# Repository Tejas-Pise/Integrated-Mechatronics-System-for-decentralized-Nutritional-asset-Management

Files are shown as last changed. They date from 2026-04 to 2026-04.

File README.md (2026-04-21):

# Integrated Mechatronics System for Decentralized Nutritional Asset Management

A cyber-physical public distribution platform for controlled, auditable, and low-friction ration dispensing. The system integrates embedded sensing and actuation (ESP32), edge orchestration (Raspberry Pi), and cloud-backed entitlement records (Firebase) to support accountable nutritional asset delivery at decentralized kiosks.

## Abstract

Conventional ration distribution pipelines in decentralized settings are vulnerable to leakage, weak traceability, and inconsistent beneficiary verification. This project proposes and implements a mechatronic kiosk architecture that combines multimodal identity checks, quota-aware dispensing logic, closed-loop gravimetric control, and transaction logging. The design objective is to reduce fraud opportunity, improve service throughput, and maintain verifiable audit trails while preserving practical deployability under constrained infrastructure.

## Research Motivation and Problem Statement

Public food distribution systems must satisfy three constraints simultaneously:

1. Identity assurance: only eligible beneficiaries should receive allocations.
2. Quantity fidelity: physical dispensed mass should match entitlement and payment policy.
3. Traceable accountability: each transaction should be reconstructable for post-hoc audit.

This repository operationalizes those constraints as a working prototype with a dual-node hardware-software stack and explicit machine-level protocol between nodes.

## Contributions

1. A modular edge architecture separating hard real-time control (ESP32) from business workflow orchestration (Raspberry Pi).
2. A serial command/event protocol for deterministic coordination of scan, verification, and dispense phases.
3. A closed-loop dispensing routine based on load-cell feedback and target-mass termination.
4. A cloud integration layer for entitlement lookup, monthly quota accounting, and transaction persistence.
5. An operator-facing kiosk interface with voice prompts, stock alerts, and payment flow scaffolding.

## High-Level System Architecture

The platform is organized into three cooperating layers:

1. Embedded control plane (ESP32): sensor IO, actuator control, weight feedback, and stock telemetry.
2. Edge orchestration plane (Raspberry Pi): user journey, identity flow, payment logic, UI/voice interaction, and cloud sync.
3. Cloud data plane (Firebase): user records, dispensed quota totals, and transaction logs.

### End-to-End Workflow

1. User initiates session at kiosk.
2. RFID scan and optional manual card entry identify candidate beneficiary.
3. Fingerprint match confirms identity linkage.
4. Cloud quota lookup determines remaining monthly entitlement and scheme type.
5. If paid scheme, UPI QR is generated and payment confirmation is awaited.
6. Raspberry Pi requests ESP32 dispensing to target mass.
7. ESP32 streams real-time weight and sends completion event.
8. Transaction is recorded and monthly dispensed counter is updated.
9. Hopper stock telemetry is periodically published and low-stock alerts are raised.

## Repository Layout

```text
.
|-- ESP32/
|   `-- ration_kiosk_esp32/
|       `-- ration_kiosk_esp32.ino
|-- Firebase/
|   `-- database_rules.json
|-- raspberry_pi/
|   |-- cloud.py
|   |-- config.py
|   |-- main.py
|   |-- payment.py
|   |-- requirements.txt
|   |-- stock.py
|   |-- uart_comm.py
|   |-- ui.py
|   `-- voice.py
`-- README.md
```

## Implementation Status (As of 2026-04-21)

Implemented:

1. ESP32 firmware with RFID, fingerprint scan routine, load-cell integration, dispensing control, and ultrasonic stock reporting.
2. Raspberry Pi orchestration flow in main controller with authentication, quota check, payment branch, dispensing callbacks, and transaction write.
3. Firebase access module for user lookup, quota calculation, transaction append, and stock updates.
4. Pygame-based kiosk UI screens and voice prompt layer.

Partially implemented or placeholder behavior:

1. Payment verification currently returns success via placeholder logic and must be replaced by gateway callback/webhook integration.
2. Manual ration-card entry UI is stubbed in controller.
3. Firebase security rules file exists but is currently empty and requires deployment-grade hardening.
4. Python dependency list is currently empty and should be pinned before production deployment.

## ESP32 Firmware Specification

Firmware file: ESP32/ration_kiosk_esp32/ration_kiosk_esp32.ino

### Sensors and Actuators

1. RFID: MFRC522 (SPI).
2. Fingerprint sensor: UART-based Adafruit-compatible module.
3. Mass measurement: HX711 + load cell.
4. Hopper level: ultrasonic distance sensor.
5. Dispense actuation: stepper motor + driver and solenoid gate.

### Control Semantics

1. Dispenser starts with tare reset, solenoid open, and stepper enable.
2. Weight samples are emitted during dispensing.
3. Dispensing halts when current weight exceeds or equals target mass.
4. Stock distance is reported periodically; threshold breach emits low-stock event.

## UART Protocol Contract

### Commands (Raspberry Pi -> ESP32)

1. SCAN_RFID
2. SCAN_FINGER
3. DISPENSE:<target_weight_kg>
4. STOP
5. TARE
6. WEIGHT?

### Events/Responses (ESP32 -> Raspberry Pi)

1. ESP32_READY
2. RFID_SCANNING
3. RFID:<UID_HEX>
4. RFID_TIMEOUT
5. FP_SCANNING
6. FP_MATCH:<finger_id>
7. FP_NO_MATCH
8. FP_TIMEOUT
9. DISPENSE_START
10. WEIGHT:<kg>
11. DISPENSE_DONE:<kg>
12. DISPENSE_STOP
13. STOCK:<distance_cm>
14. STOCK_LOW:<distance_cm>

## Raspberry Pi Software Architecture

### Module Responsibilities

1. raspberry_pi/main.py: session state flow, authentication pipeline, scheme-specific branching, and transaction finalization.
2. raspberry_pi/uart_comm.py: serial transport abstraction, callback dispatch, blocking scan primitives, and dispense streaming callbacks.
3. raspberry_pi/cloud.py: Firebase initialization and CRUD-style service methods.
4. raspberry_pi/payment.py: UPI QR generation, payment polling scaffold, and pricing computation.
5. raspberry_pi/stock.py: stock event handling, cloud stock update, and external alert trigger.
6. raspberry_pi/ui.py: touchscreen workflows implemented in pygame.
7. raspberry_pi/voice.py: non-blocking spoken prompts via gTTS with system fallback.
8. raspberry_pi/config.py: deployment constants for serial, pricing, UI dimensions, and policy thresholds.

### Logical State Machine

At a conceptual level, the controller behaves as a finite-state process:

1. S0 Idle/Welcome
2. S1 Identity Capture (RFID/manual card)
3. S2 Biometric Verification
4. S3 Cloud Quota Evaluation
5. S4 Scheme Branch (FREE or PAID)
6. S5 Payment (PAID branch only)
7. S6 Dispensing
8. S7 Transaction Commit
9. S8 Session Completion -> S0

Any validation failure routes to error display and restart from S0.

## Data Model (Firebase, Current Usage)

Observed key paths in current code:

1. users/<ration_card_no>
2. users/<ration_card_no>/dispensed/<YYYY-MM>
3. transactions/<ration_card_no>/<auto_key>
4. stock/hopper_distance_cm
5. stock/last_updated

Representative user fields:

1. name
2. ration_card
3. rfid_uid
4. fingerprint_id
5. monthly_quota_kg
6. scheme_type
7. family_size

## Experimental and Deployment Prerequisites

### Hardware

1. ESP32 dev board
2. Raspberry Pi 3/4/5
3. MFRC522 RFID module
4. UART fingerprint sensor
5. HX711 + calibrated load cell
6. Ultrasonic sensor
7. Stepper motor and driver
8. Solenoid actuator
9. Protected power stage, fusing, and relay/driver isolation where required

### Software

1. Arduino IDE 2.x (ESP32 toolchain)
2. Python 3.10+ on Raspberry Pi
3. Firebase project with Realtime Database
4. Linux utilities for audio playback (for example mpg123 or espeak fallback)

## Reproducible Setup Procedure

### A. Flash and Validate ESP32

1. Open ESP32/ration_kiosk_esp32/ration_kiosk_esp32.ino in Arduino IDE.
2. Install required libraries: MFRC522, Adafruit Fingerprint Sensor Library, HX711.
3. Select ESP32 Dev Module and set baud to 115200.
4. Confirm pin mapping against physical wiring.
5. Upload and verify serial startup event ESP32_READY.

### B. Configure Raspberry Pi Runtime

1. Create Python virtual environment.
2. Install dependencies required by current modules (serial, pygame, firebase-admin, qrcode, pillow, gTTS, requests).
3. Place Firebase service account JSON at raspberry_pi/firebase_service_key.json or update path in cloud module.
4. Update raspberry_pi/config.py with project-specific database URL, pricing, UART port, and payment identity.
5. Launch controller from raspberry_pi/main.py.

### C. Configure Firebase

1. Populate beneficiary records with ration card, RFID UID, fingerprint ID, quota, and scheme type.
2. Add database security rules before field testing.
3. Validate read/write privileges using least-privilege principle.

## Calibration and Validation Protocol

For defensible performance reporting, calibrate and evaluate under controlled conditions.

1. Load-cell calibration:
   Use at least three known masses spanning expected dispense range and fit scale factor.
2. Dispense accuracy test:
   For each target mass, run repeated trials and report mean absolute error and standard deviation.
3. Biometric flow reliability:
   Measure false rejection events and timeout rate across user cohorts.
4. End-to-end latency:
   Report timing from session start to dispense completion under free and paid branches.
5. Stock alert validity:
   Confirm threshold crossing behavior against measured hopper levels.

Useful metrics include:

1. Mean dispense error (kg)
2. 95th percentile session duration (s)
3. Successful first-attempt biometric rate (%)
4. Cloud commit success rate (%)
5. Stock alert precision/recall against manual ground truth

## Security, Safety, and Ethical Considerations

1. Identity data is sensitive: store only required biometric references and enforce strict access control.
2. Payment and transaction data require tamper-evident logging and secure transport.
3. Serial protocol should be hardened against malformed or replayed command payloads.
4. Power electronics must include actuator-safe defaults and fault handling on reboot.
5. Inclusion concerns: provide assisted flow for users with fingerprint/RFID acquisition difficulties.

## Limitations

1. Payment confirmation path is currently non-production and must be replaced with verifiable gateway reconciliation.
2. Manual card-number input is currently a stub.
3. No formal automated test suite is committed yet for UART simulation and integration regression.
4. Firebase rule set and dependency lockfile are not yet finalized.

## Roadmap

1. Replace payment placeholder with webhook-verified transaction state machine.
2. Add robust serial parser with checksum/framing and explicit error codes.
3. Implement local offline queue with eventual cloud reconciliation.
4. Introduce automated hardware-in-the-loop and protocol-level integration tests.
5. Add operator analytics dashboard for multi-kiosk monitoring.

## Recommended Citation

If you use this repository in an academic report, thesis, or publication, cite it with commit hash and access date. Suggested BibTeX template:

```bibtex
@misc{ims_dnam_2026,
  title        = {Integrated Mechatronics System for Decentralized Nutritional Asset Management},
  author       = {Project Team},
  year         = {2026},
  howpublished = {Git repository},
  note         = {Accessed: YYYY-MM-DD, commit: <hash>}
}
```

## License and Governance

No license file is currently committed. Add an explicit license (for example MIT, BSD-3-Clause, or Apache-2.0) before external distribution.

## Contact

Add maintainer names, institutional affiliation, and contact channel for deployment collaboration and field validation studies.

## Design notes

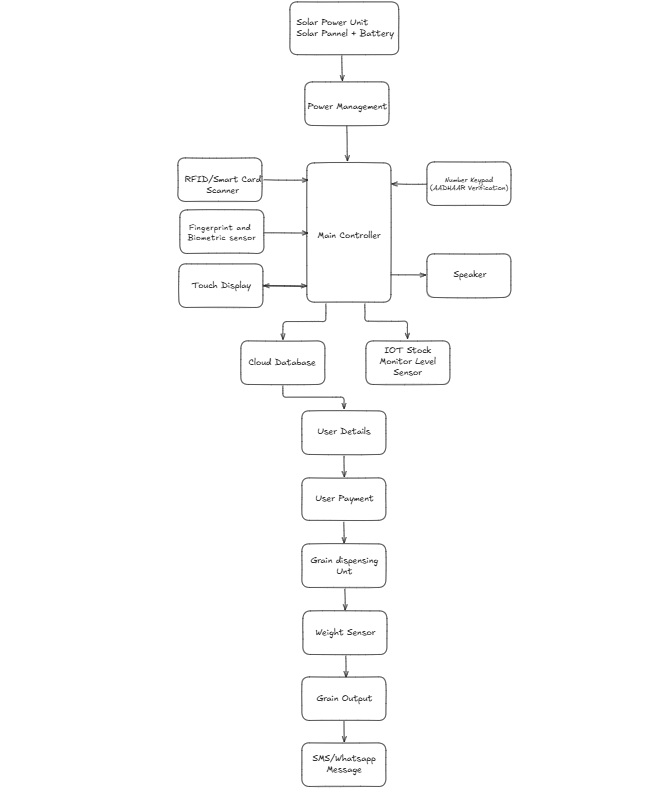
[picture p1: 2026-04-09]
Circuit and Block diagram/Block-Diagram_Integrated-Mechatronic-System-for-Decentralized-Nutritional-Asset-Management.png

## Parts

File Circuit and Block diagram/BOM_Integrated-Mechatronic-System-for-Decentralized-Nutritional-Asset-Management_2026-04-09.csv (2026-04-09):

ID | Name | Designator | Footprint | Quantity | Manufacturer Part | Manufacturer | Supplier | Supplier Part | Price | Pins | Contributor | JLCPCB Part Class | description | link | sourceId | subpart_no
1 | 1N4007 | D1 | DO-41_BD2.4-L4.7-P8.70-D0.9-RD | 1 | 1N4007 | SEMTECH | LCSC | C106903 | 0.02 | 2 | LCEDA_Lib
2 | SCHLIB_12V-Solenoid-Lock_2024-10-13 | JP1 | SCREWTERMINAL-3.5MM-2_LOCK | 1 |  |  | AI-thinker |  |  | 2 | mhaikal4990 |  | Standard 2-pin 0.1 header. Use with
3 | RC522 | M1 | RFID-RC522-CONNECTOR-PLS8 | 1 |  |  |  |  |  | 8 | wolframore |  | RFID-RC522
4 | MD-RASPBERRY_PI_4B COPY | RPI1 | MD-HDR-20X2/2.54 | 1 | Raspberry Pi 4 Model B 2019 Quad Core 64 Bit WiFi Bluetooth (4GB) | Raspberry Pi | Adafruit | 3775 |  | 40 | Maksim Davletchin |  |  | https://www.raspberrypi.com/products/raspberry-pi-4-model-b/
5 | speaker | SP1 | SPEAKER | 1 |  |  | LCSC |  |  | 2 | erwin.hirales
6 | ESP32_WROOM_30PIN_SAJAT1 | U1 | ESP32 DEVKIT V1 30 PIN DEVBOARD | 1 |  |  |  |  |  | 30 | albertm3
7 | FINGERPRINT-R307 COPY | U2 | SIL-6 | 1 | R307 |  |  |  |  | 6 | syahirakurnia95 |  |  |  |  | 1
8 | HX711-MODULE | U3 | HX711-MODULE | 1 |  |  |  |  |  | 10 | marsy112
9 | NEMA17- | U4 | NEMA17 | 1 |  |  |  |  |  | 4 | feedefr
10 | A4988 | U5 | DIP-16_L20.3-W15.2-P2.54_LS12.7_A4988 | 1 | A4988 | null | LCSC | C9900168373 |  | 16 | lcsc
11 | DFPlayer Mini | U6 | DFPLAYER MINI | 1 |  |  |  |  |  | 16 | sanadbaligeri |  |  |  | cKDVP7pjB
12 | LM2596S BUCK CONVERTER v1 | U7 | LM2596S BUCK CONVERTER V2 | 1 |  |  |  |  |  | 4 | Lailatus sya\'diyah
13 | HC-SR04 | U8 | TH_HC-SR04V | 1 | HC-SR04 | Universal Microelectronics | LCSC | C19857336 | 5.217 | 4 | lcsc | Extended Part
14 | 1-CHANNEL_RELAY_MODULE COPY | U9 | RELAY MODULE 1 RELAYS | 1 | 1-Channel 5V Relay Module w/ Opto-isolator |  |  | SKU: 223429 |  | 6 | jousterde1 |  |  | http://www.volumerate.com/product/1-channel-5v-relay-module-w-opto-isolator-red-blue-223429
15 | 12VDC | V1 | HDR1X2 | 1 |  |  |  |  |  | 2 | Ajnevs

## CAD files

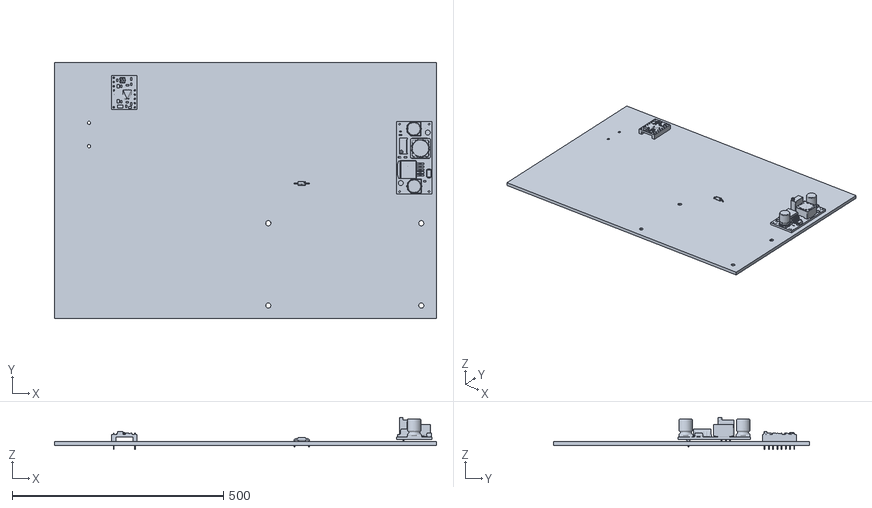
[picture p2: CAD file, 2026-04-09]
Circuit and Block diagram/OBJ_PCB_Integrated-Mechatronic-System-for-Decentralized-Nutritional-Asset-Management_2026-04-09/OBJ_PCB_Integrated Mechatronic System for Decentralized Nutritional Asset Man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
904.3 x 605.1 x 76.1

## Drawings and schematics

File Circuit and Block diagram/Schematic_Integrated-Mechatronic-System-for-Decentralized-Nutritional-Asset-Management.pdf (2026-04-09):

# USBESP32-WROOM-32

# VDD 10 1B11 1A12 2A13 2B14 GND 15 VMOT 16

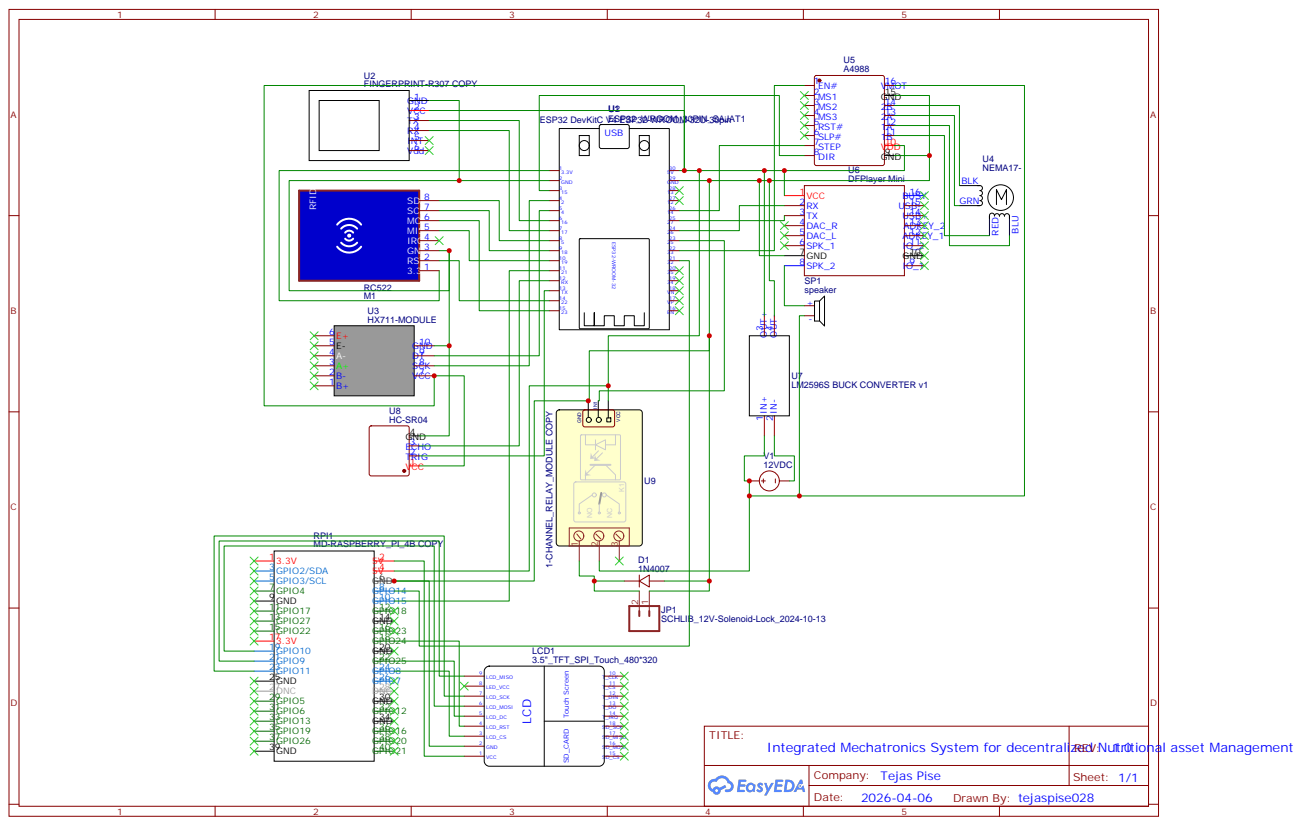
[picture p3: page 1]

Integrated Mechatronics System for decentralized Nutritional asset Management REV: 1.0

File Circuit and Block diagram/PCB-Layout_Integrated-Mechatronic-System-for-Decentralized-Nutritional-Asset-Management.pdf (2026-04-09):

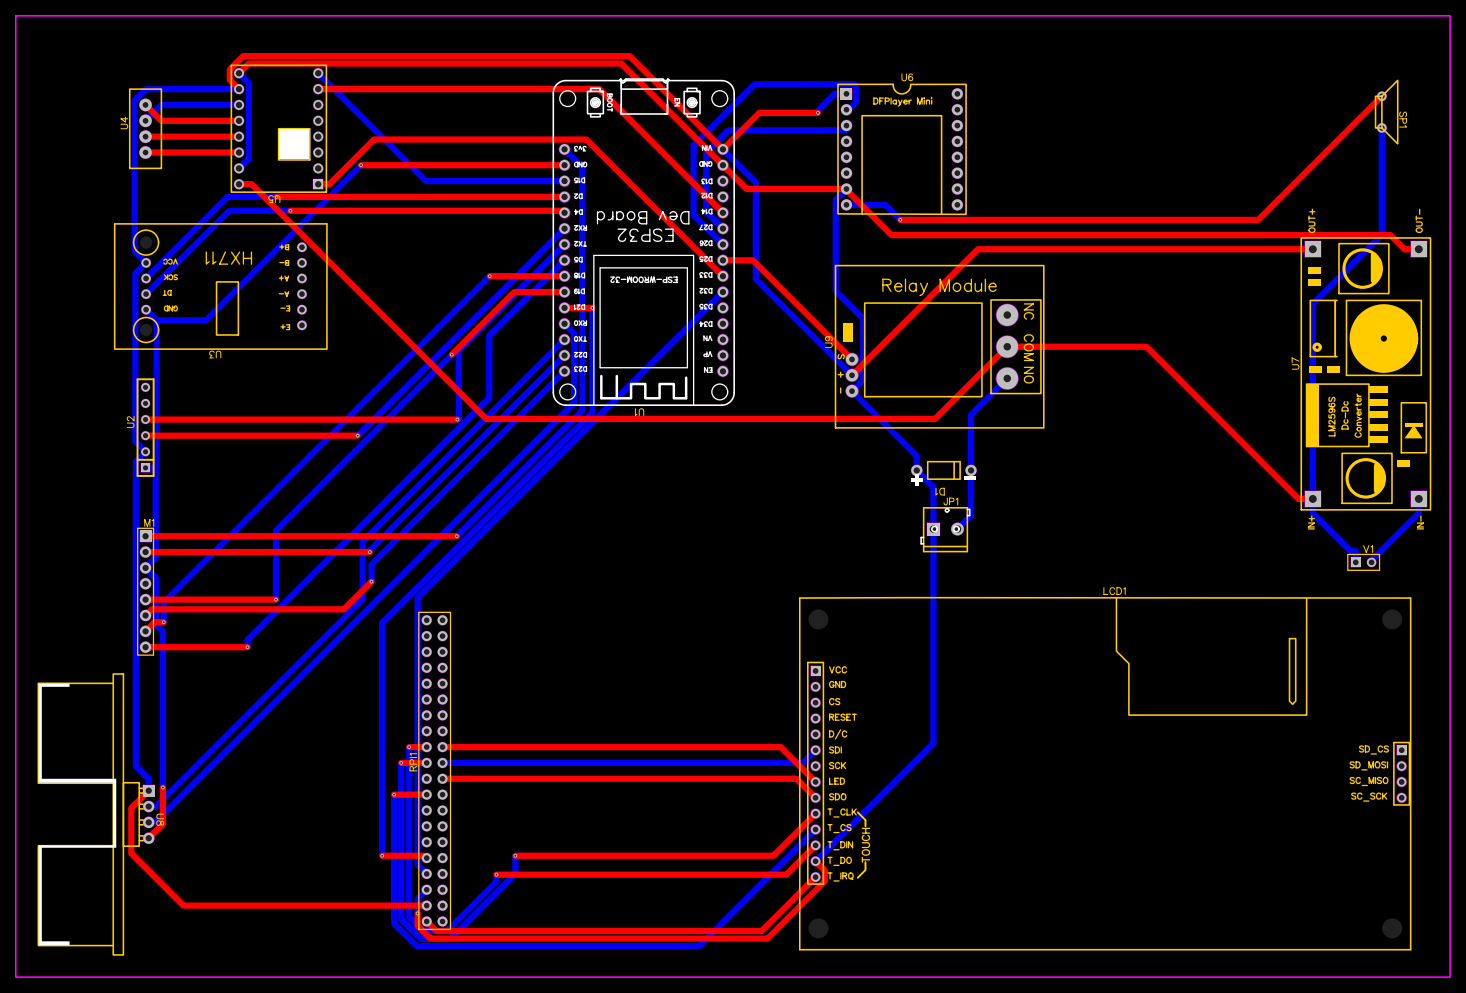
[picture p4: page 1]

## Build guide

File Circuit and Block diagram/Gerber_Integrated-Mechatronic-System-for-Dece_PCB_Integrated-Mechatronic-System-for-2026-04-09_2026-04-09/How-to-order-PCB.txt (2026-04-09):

How to Order PCB

Please refer to:
https://docs.easyeda.com/en/PCB/Order-PCB

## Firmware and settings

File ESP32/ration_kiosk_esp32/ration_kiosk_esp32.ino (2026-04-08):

// ============================================================
//  SMART RATION KIOSK — ESP32 FIRMWARE
//  File: ration_kiosk_esp32.ino
//  IDE: Arduino IDE 2.x
//  Board: ESP32 Dev Module
// ============================================================

#include <SPI.h>
#include <MFRC522.h>
#include <Adafruit_Fingerprint.h>
#include <HX711.h>

// ── Pin Definitions ─────────────────────────────────────────
#define RFID_SS_PIN   5
#define RFID_RST_PIN  22

#define FP_TX_PIN     16
#define FP_RX_PIN     17

#define HX711_DT_PIN  4
#define HX711_SCK_PIN 2

#define ULTRASONIC_TRIG 13
#define ULTRASONIC_ECHO 12

#define DFPLAYER_RX   26
#define DFPLAYER_TX   27

#define STEPPER_STEP  14
#define STEPPER_DIR   15
#define STEPPER_EN    33

#define SOLENOID_PIN  25

// ── UART with Pi (GPIO21=TX, GPIO32=RX) ─────────────────────
#define PI_UART_TX    21
#define PI_UART_RX    32
HardwareSerial PiSerial(1);

// ── Fingerprint UART ─────────────────────────────────────────
HardwareSerial fpSerial(2);
Adafruit_Fingerprint finger = Adafruit_Fingerprint(&fpSerial);

// ── RFID ────────────────────────────────────────────────────
MFRC522 rfid(RFID_SS_PIN, RFID_RST_PIN);

// ── Load Cell ───────────────────────────────────────────────
HX711 scale;

// ── State ───────────────────────────────────────────────────
float targetWeight   = 0.0;
bool  dispensing     = false;
bool  stepperRunning = false;
String currentUID    = "";

// ── Calibration factor (calibrate once) ─────────────────────
float CALIBRATION_FACTOR = 2280.0;

// ============================================================
void setup() {
  Serial.begin(115200);
  PiSerial.begin(115200, SERIAL_8N1, PI_UART_RX, PI_UART_TX);

  // RFID
  SPI.begin();
  rfid.PCD_Init();

  // Fingerprint
  fpSerial.begin(57600, SERIAL_8N1, FP_TX_PIN, FP_RX_PIN);
  finger.begin(57600);

  // Load Cell
  scale.begin(HX711_DT_PIN, HX711_SCK_PIN);
  scale.set_scale(CALIBRATION_FACTOR);
  scale.tare();

  // Ultrasonic
  pinMode(ULTRASONIC_TRIG, OUTPUT);
  pinMode(ULTRASONIC_ECHO, INPUT);

  // Stepper
  pinMode(STEPPER_STEP, OUTPUT);
  pinMode(STEPPER_DIR,  OUTPUT);
  pinMode(STEPPER_EN,   OUTPUT);
  digitalWrite(STEPPER_EN, HIGH); // disabled by default

  // Solenoid
  pinMode(SOLENOID_PIN, OUTPUT);
  digitalWrite(SOLENOID_PIN, LOW);

  Serial.println("ESP32 Ready");
  PiSerial.println("ESP32_READY");
}

// ============================================================
void loop() {
  handlePiCommands();
  if (dispensing) runDispenser();
  checkStock();
  delay(10);
}

// ── Pi Command Handler ───────────────────────────────────────
void handlePiCommands() {
  if (!PiSerial.available()) return;
  String cmd = PiSerial.readStringUntil('\n');
  cmd.trim();

  if (cmd == "SCAN_RFID") {
    scanRFID();
  } else if (cmd == "SCAN_FINGER") {
    scanFingerprint();
  } else if (cmd.startsWith("DISPENSE:")) {
    targetWeight = cmd.substring(9).toFloat();
    startDispensing();
  } else if (cmd == "STOP") {
    stopDispensing();
  } else if (cmd == "TARE") {
    scale.tare();
    PiSerial.println("TARE_DONE");
  } else if (cmd == "WEIGHT?") {
    float w = scale.get_units(3);
    PiSerial.println("WEIGHT:" + String(w, 2));
  }
}

// ── RFID ────────────────────────────────────────────────────
void scanRFID() {
  PiSerial.println("RFID_SCANNING");
  unsigned long start = millis();
  while (millis() - start < 10000) { // 10 second timeout
    if (!rfid.PICC_IsNewCardPresent() || !rfid.PICC_ReadCardSerial()) {
      delay(50);
      continue;
    }
    currentUID = "";
    for (byte i = 0; i < rfid.uid.size; i++) {
      if (rfid.uid.uidByte[i] < 0x10) currentUID += "0";
      currentUID += String(rfid.uid.uidByte[i], HEX);
    }
    currentUID.toUpperCase();
    rfid.PICC_HaltA();
    PiSerial.println("RFID:" + currentUID);
    return;
  }
  PiSerial.println("RFID_TIMEOUT");
}

// ── Fingerprint ──────────────────────────────────────────────
void scanFingerprint() {
  PiSerial.println("FP_SCANNING");
  int id = getFingerprintID();
  if (id > 0) {
    PiSerial.println("FP_MATCH:" + String(id));
  } else if (id == -2) {
    PiSerial.println("FP_NO_MATCH");
  } else {
    PiSerial.println("FP_TIMEOUT");
  }
}

int getFingerprintID() {
  unsigned long start = millis();
  while (millis() - start < 10000) {
    int p = finger.getImage();
    if (p == FINGERPRINT_OK) {
      p = finger.image2Tz();
      if (p == FINGERPRINT_OK) {
        p = finger.fingerFastSearch();
        if (p == FINGERPRINT_OK) return finger.fingerID;
        return -2; // no match
      }
    }
    delay(100);
  }
  return -1; // timeout
}

// ── Dispenser ────────────────────────────────────────────────
void startDispensing() {
  scale.tare();
  digitalWrite(SOLENOID_PIN, HIGH);
  digitalWrite(STEPPER_EN, LOW);
  digitalWrite(STEPPER_DIR, HIGH);
  dispensing = true;
  PiSerial.println("DISPENSE_START");
}

void stopDispensing() {
  dispensing = false;
  digitalWrite(SOLENOID_PIN, LOW);
  digitalWrite(STEPPER_EN, HIGH);
  PiSerial.println("DISPENSE_STOP");
}

void runDispenser() {
  float currentWeight = scale.get_units(5);
  PiSerial.println("WEIGHT:" + String(currentWeight, 2));

  if (currentWeight >= targetWeight) {
    stopDispensing();
    PiSerial.println("DISPENSE_DONE:" + String(currentWeight, 2));
    return;
  }

  // Step motor one pulse
  digitalWrite(STEPPER_STEP, HIGH);
  delayMicroseconds(800);
  digitalWrite(STEPPER_STEP, LOW);
  delayMicroseconds(800);
}

// ── Stock Monitor ────────────────────────────────────────────
void checkStock() {
  static unsigned long lastCheck = 0;
  if (millis() - lastCheck < 5000) return;
  lastCheck = millis();

  float dist = getUltrasonicDistance();
  PiSerial.println("STOCK:" + String(dist, 1));

  if (dist > 25.0) { // hopper getting low (adjust per your hopper size)
    PiSerial.println("STOCK_LOW:" + String(dist, 1));
  }
}

float getUltrasonicDistance() {
  digitalWrite(ULTRASONIC_TRIG, LOW);
  delayMicroseconds(2);
  digitalWrite(ULTRASONIC_TRIG, HIGH);
  delayMicroseconds(10);
  digitalWrite(ULTRASONIC_TRIG, LOW);
  long dur = pulseIn(ULTRASONIC_ECHO, HIGH, 30000);
  return (dur * 0.034) / 2.0;
}

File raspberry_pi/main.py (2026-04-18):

# main.py — Main kiosk controller
# Run with: python3 main.py

import time
import sys
import threading
import config
from uart_comm import UARTComm
from cloud     import (get_user_by_rfid, get_user_by_ration_card,
                       verify_fingerprint_id, get_monthly_quota,
                       record_transaction)
from payment   import generate_upi_qr, wait_for_payment, calculate_price
from voice     import speak
from stock     import StockMonitor
from ui        import KioskUI, pygame

class RationKiosk:
    def __init__(self):
        self.uart  = UARTComm()
        self.ui    = KioskUI()
        self.stock = StockMonitor(self.uart, self._on_stock_alert)
        self.stock.start()
        time.sleep(1)  # let ESP32 boot

    # ── Entry point ──────────────────────────────────────────
    def run(self):
        speak("welcome")
        while True:
            try:
                self._flow_authenticate()
            except KeyboardInterrupt:
                break
            except Exception as e:
                print(f"Error: {e}")
                self.ui.screen_error(str(e))
                speak("error")
                time.sleep(3)

    # ── Step 1 + 2: Auth + Biometric ────────────────────────
    def _flow_authenticate(self):
        while True:
            speak("scan_rfid")
            btn = self.ui.screen_welcome()
            start = time.time()

            # Wait for RFID or button touch (enter card manually)
            rfid_uid = self.uart.scan_rfid(timeout=15)

            if rfid_uid:
                user = get_user_by_rfid(rfid_uid)
            else:
                # Manual ration card entry (keyboard / numpad)
                card_no = self._get_manual_input("Enter Ration Card No:")
                user = get_user_by_ration_card(card_no) if card_no else None

            if not user:
                self.ui.screen_error("Card not found in database.")
                time.sleep(2)
                continue

            # ── Step 2: Fingerprint ──────────────────────────
            fp_verified = False
            for attempt in range(1, 4):
                self.ui.screen_fingerprint(attempt)
                speak("scan_finger")
                fp_id = self.uart.scan_fingerprint(timeout=10)
                if fp_id and verify_fingerprint_id(user["ration_card"], fp_id):
                    fp_verified = True
                    speak("fp_ok")
                    break
                speak("fp_fail")
                time.sleep(1)

            if not fp_verified:
                self.ui.screen_error("Fingerprint verification failed.")
                time.sleep(2)
                continue

            # ── Step 3: Cloud data ───────────────────────────
            speak("cloud_checking")
            quota = get_monthly_quota(user["ration_card"])

            if quota.get("remaining_kg", 0) <= 0:
                speak("no_quota")
                self.ui.screen_error("Monthly quota exhausted.")
                time.sleep(3)
                continue

            # ── Step 4: Show info + proceed to dispense ──────
            ok_btn, no_btn = self.ui.screen_user_info(user, quota)
            choice = self._wait_for_touch([ok_btn, no_btn])
            if choice == 1:  # Cancel
                continue

            self._flow_dispense(user, quota)
            return  # Loop back to welcome

    # ── Step 5–9: Dispense flow ──────────────────────────────
    def _flow_dispense(self, user: dict, quota: dict):
        scheme = quota.get("scheme_type", "PAID")
        is_free = scheme in config.FREE_SCHEME_TYPES
        grain  = "wheat"  # default; can add selection screen

        # Grain selection for paid users
        if not is_free:
            grain = self._select_grain()
            if not grain:
                return

        # Weight selection (simple fixed options)
        weight_kg = min(quota["remaining_kg"], 5.0)  # max 5kg per visit

        # Payment
        amount = 0.0
        txn_ref = "FREE"

        if not is_free:
            speak("scheme_paid")
            amount  = calculate_price(grain, weight_kg)
            qr_img, txn_ref = generate_upi_qr(
                amount, grain, user["ration_card"]
            )
            speak("payment_qr")
            confirm_btn, cancel_btn = self.ui.screen_payment(qr_img, amount, grain)
            choice = self._wait_for_touch([confirm_btn, cancel_btn], timeout=120)
            if choice == 1:  # Cancel
                return
            payment_ok = wait_for_payment(txn_ref, amount)
            if not payment_ok:
                self.ui.screen_error("Payment not confirmed.")
                time.sleep(3)
                return
            speak("payment_ok")
        else:
            speak("scheme_free")

        # ── Dispense ─────────────────────────────────────────
        speak("dispensing")
        done_event   = threading.Event()
        final_weight = {"w": 0.0}

        def on_weight(w):
            self.ui.screen_dispensing(grain, w, weight_kg)
            self.ui.flip()

        def on_done(w):
            final_weight["w"] = w
            done_event.set()

        self.uart.dispense(weight_kg, on_weight=on_weight, on_done=on_done)
        done_event.wait(timeout=120)

        actual_kg = final_weight["w"]
        speak("dispense_done")

        # ── Record transaction ────────────────────────────────
        mode = "FREE" if is_free else "PAID"
        record_transaction(
            user["ration_card"], grain, actual_kg,
            amount if not is_free else 0.0,
            mode, txn_ref
        )

        self.ui.screen_done(grain, actual_kg, amount, mode)
        time.sleep(4)

    # ── Helpers ──────────────────────────────────────────────
    def _select_grain(self) -> str | None:
        """Show grain selection, return chosen grain key."""
        btns = self.ui.screen_grain_select(config.GRAIN_PRICES)
        while True:
            pos = self.ui.get_touch()
            if not pos:
                time.sleep(0.05)
                continue
            for grain, rect in btns.items():
                if rect.collidepoint(pos):
                    return grain
            time.sleep(0.05)

    def _wait_for_touch(self, rects: list, timeout: int = 60) -> int:
        """Wait for touch on one of the rects. Returns 0-indexed match."""
        start = time.time()
        while time.time() - start < timeout:
            pos = self.ui.get_touch()
            if pos:
                for i, r in enumerate(rects):
                    if r.collidepoint(pos):
                        return i
            time.sleep(0.05)
        return -1  # timeout

    def _get_manual_input(self, prompt: str) -> str | None:
        """Simple on-screen keyboard placeholder — extend with pygame keyboard."""
        # For now: return None and rely on RFID only
        # TODO: implement pygame on-screen numpad
        return None
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

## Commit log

2026-04-09 Add project assets
    [BOM_Integrated-Mechatronic-System-for-Decentralized-Nutritional-Asset-Management_2026-04-09.csv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]
2026-04-12 Update Raspberry Pi UI and stock logic
